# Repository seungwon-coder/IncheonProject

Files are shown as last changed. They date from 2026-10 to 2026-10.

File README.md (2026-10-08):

# PBV 생산 자동화 프로젝트 포트폴리오

PBV 생산 자동화 팀 프로젝트의 Dobot·Vision·PLC·SCADA·MES·SolidWorks 자료입니다. 본인의 Dobot Magician 4대 통합 제어와 전체 설비 조립·배치 작업, 팀원의 Vision·PLC·SCADA·MES 개발 자료를 구분해 소개합니다.

## 주요 구현
- 로봇별 독립 Worker 프로세스 및 오류 격리
- PLC·KEPServerEX OPC-UA START/READY/RUNNING/FINISH/ERROR 연동
- 수동·자동 운전 GUI, 좌표 티칭, 경로 확인
- 비전 분류 결과에 따른 반환과 차량 하부 창고 입출고
- SCADA 좌표 32개 전송 및 오래된 좌표 제외

## 읽는 순서
1. [프로젝트 개요와 담당 역할](Dobot/docs/PORTFOLIO_PROJECT_OVERVIEW.md)
2. [실행 방법과 개발 문서](Dobot/README.md)
3. [OPC-UA 태그](Dobot/docs/ROBOT_OPCUA_TAGS.md)

## 공개 범위
소스 기준: 로컬 Dobot main의 ce25ddf (2026-10-02). 공개본은 별도 새 이력으로 게시하여 비공개 저장소의 과거 이력을 포함하지 않습니다.

실제 로봇 시리얼번호, 현장 티칭 좌표, 내부 서버 IP와 재고 상태는 예시값으로 바꿨습니다. 내부 점검 메모와 제조사 SDK 바이너리/래퍼는 포함하지 않습니다. 팀 산출물은 아래 각 폴더의 공개 범위와 담당 설명을 따릅니다. 제조사 SDK는 공식 배포처에서 별도로 준비하세요. 원본 개발 문서의 SDK 포함 안내는 원본 작업 환경에 대한 설명입니다.

자동시험과 실제 설비 시운전 결과는 구분합니다. 원본 환경의 전체 자동시험은 asyncua 미설치 때문에 1개 모듈을 로딩하지 못했습니다. 공개본의 샘플 설정은 실제 장비 운전 설정이 아니며 현장 연결·티칭이 필요합니다.

일괄 오픈소스 라이선스는 부여하지 않았습니다. 코드 공개와 제3자 자료의 재배포 권한은 별개입니다.

## Vision 코드와 역할 구분
[Vision V13.29 공개용 코드·문서](Vision/README.md)를 추가했습니다. Vision 알고리즘 개발은 팀원이 담당했으며, 포트폴리오 소유자는 Dobot 제어·Vision 결과의 로봇 공정 연동과 검증·통합 지원을 담당했습니다. 모델 바이너리·전체 데이터셋·현장 운영 설정은 포함하지 않습니다. 사용 모델은 [모델 안내](Vision/MODEL_INFO.md)에 기록합니다.

### Vision V13.29 갱신
V3는 시트별 ROI에서 갈색 계열 픽셀 비율로 제품 유무를 확인하고 주문별 수량과 LED ON을 검사합니다. V1~V3 결과는 FINISH/NG/ERROR 중 하나를 1초 출력하며 V4 CLASS_RESULT 초기화는 PLC가 담당합니다. 실제 장치 경로·ROI·색상 기준은 공개용 설정에서 제거했습니다. 모델 4개와 기존 best.pt의 해시 동일성을 확인했으며 바이너리는 제외했습니다. 선택한 모의 시험 5개가 통과했고 실제 설비 운전은 이번 갱신에서 검증하지 않았습니다.

## SolidWorks 전체 설비 모델
[SolidWorks 모델링 자료](SolidWorks/README.md)를 추가했습니다. 전체 설비 조립과 장치 배치를 본인이 구성했으며 개별 부품에는 제조사 제공·참조 모델이 포함될 수 있습니다. OldVer를 제외한 원본 275개를 Git LFS로 보관합니다.

## PLC · SCADA · MES (2026-10-08 공개)
- [PLC 래더 PDF 및 날짜별 명령 CSV](PLC/README.md): 10월 2일 PDF와 9월 25일 CSV의 시점을 구분합니다. 최신 GXW 원본은 미포함입니다.
- [SCADA 보조 코드·DB 테이블·화면·운영 안내](SCADA/README.md): CIMON/KEPServer 원본 바이너리와 운영 DB는 미포함입니다.
- [MES 및 106개 태그 수집기](MES/README.md): 현재 로컬 소스를 기준으로 공개용 설정을 적용했습니다. SCADA 주문 읽기는 구현, 재생산 명령 쓰기/ACK와 ERP 전송은 미연결입니다.

SCADA·MES·PLC는 팀 산출물입니다. MES는 김동진 프로젝트 산출물을 기반으로 하며 본인의 Dobot 제어와 연결되는 지점을 설명합니다. 제품별 공정 이력과 재고 일부는 작업자 확인 기록이고 TEST/PRODUCTION은 저장 데이터 분류입니다.
공개본은 실제 계정·내부 주소·운영 데이터·로그를 제외하고 localhost 설정 예시를 사용합니다. 이번 게시에서 실제 설비 운전과 GX Works2 컴파일을 수행하지 않았습니다.

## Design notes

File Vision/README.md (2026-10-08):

# PV5 Vision V13.29 — 공개용 코드

PBV 생산 자동화 팀 프로젝트의 Vision 검사와 PLC·로봇 연동을 설명하는 공개용 선별본입니다. V13.10 공개본을 `pv5_control_hub_v13_29`의 코드로 갱신했습니다. 원본 현장 파일은 수정하지 않았습니다.

## 역할과 기여
- Vision 담당 팀원: 학습 데이터 준비, 모델 학습, 객체 검출·검사 판정 알고리즘 개발.
- 포트폴리오 소유자: Dobot 제어를 주 담당으로 맡아 PLC를 통해 전달되는 Vision 결과와 로봇 동작의 연결 조건을 검토. Vision 4 코드에 따른 Dobot_4 반환·창고 입고와 별도 출고 처리는 [Dobot 코드](../Dobot/)에 구현.
- 통합 지원: 팀장으로서 장치 간 인터페이스 조율, 공정 연동 조건·로봇 제어 로직 검증, 통합 시운전 지원.

Vision 알고리즘 개발과 로봇 연동·검증 지원은 구분하여 기록합니다.

## 검사 역할
| 구분 | 현재 판정 방식 |
|---|---|
| V1 | YOLO 램프 형상을 주문 ROUND/EDGE와 비교 |
| V2 | 검출한 시트 영역의 LAB 색상을 COCOA/DARK 기준색과 비교 |
| V3 | 시트1·시트2 ROI에서 갈색 계열 픽셀 비율로 제품 유무 판정. 주문별 시트 수량과 LED ON을 확인 |
| V4 | 단품 분류: 2 ROUND, 3 EDGE, 4 COCOA, 5 DARK, 6 차체. 빈 지그·미인식·색상 미분류·다중 부품은 0과 ERROR |

V3는 정확한 COCOA/DARK 종류나 램프 형상을 최종 판정에 사용하지 않습니다. LED 전용 ROI의 현재 밝기로 ON/OFF를 판단합니다. V13.29는 정규화 ROI 좌표를 실제 프레임 픽셀로 변환해 기준색 저장 오류를 수정합니다.

## 구조와 기능
카메라 4대 → Core 서버(카메라 단독 소유·YOLO/OpenCV 판정·OPC-UA·HTTP) → 제어판·웹·SCADA

시트1·시트2·LED 다각형 ROI 편집, 색상 기준 보정, 사용자 설정 영구 저장, OPC 자동 재연결을 지원합니다. 제어판 종료와 Core 종료는 별개입니다.

## PLC 신호 규칙
- V1~V3: 양품 FINISH, 불량 NG, 오류 ERROR 중 하나만 ON. 판정 직전 RUNNING OFF.
- V4: 정상 분류값 2~6과 FINISH, 비정상은 분류값 0과 ERROR.
- 결과 비트는 기본 1초 출력 후 OFF. PLC는 결과를 놓치지 않도록 저장해야 합니다.
- V4 CLASS_RESULT 초기화는 PLC 담당이며 Python은 JIG_Dispose를 읽거나 기다리지 않습니다.
- START OFF 확인 후 다음 ON에서 검사. 설정상 검사 제한시간 3초, 안정 판정 5프레임, V3 LED 점등 대기 0초.

## 공개용 설정과 실행
내부 IP는 localhost로, 카메라 장치 경로는 빈 값으로 바꿨습니다. 현장 ROI와 기준색은 제거했습니다. 실제 검사 전에 카메라·태그·모델·시트1/2 및 LED ROI·기준색을 설정해야 합니다. V3 객체 ROI는 빈 값이므로 그대로 정상 검사 가능한 현장 설정이 아닙니다.

```powershell
cd Vision
python -m pip install -r requirements.txt
python control_panel.py
```
Windows에서는 START_APP.vbs로 제어판을 시작할 수도 있습니다. Core 시작 후 `http://127.0.0.1:5000/`에서 4분할 영상을 확인합니다. 실제 PLC 쓰기는 기본 OFF이며 현장 검증과 작업자 승인 후 전환합니다.

기준색·ROI는 `%LOCALAPPDATA%/PV5_VISION_CONTROL/user_settings.json`에 저장되어 버전 폴더가 바뀌어도 복원될 수 있습니다. 기존 현장 설정은 별도 백업·검토하세요.

## 모델과 검증
[모델 안내](MODEL_INFO.md)에 동일 파일 여부를 기록했습니다. 모델 바이너리·전체 학습 데이터·운전 로그·현장 설정·내부 작업 프롬프트와 다른 PLC 도구 ZIP은 공개본에 포함하지 않습니다.

`test_*.py`의 일부는 이미지 처리 라이브러리나 장치 열거를 요구합니다. 전체를 장비 없는 시험으로 취급하지 않습니다. 이번 공개 작업은 문법·설정 구조와 선택한 모의 시험만 확인하며 실제 카메라·모델 정확도·PLC 연속운전을 검증한 것은 아닙니다. V13.10 이력은 Git 기록에 남습니다. 일괄 오픈소스 라이선스를 추가하지 않았습니다.

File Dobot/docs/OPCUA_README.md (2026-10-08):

# KEPServerEX OPC UA 통신

기본 접속 주소: `opc.tcp://127.0.0.1:49320`

## 실행 (Python 3.10 이상)

프로젝트 폴더에서 실행합니다.

```powershell
python -m pip install -r requirements-opcua.txt
python kepserver_opcua.py check
python kepserver_opcua.py browse --depth 3
```

ROBOT_I/O와 VISION_I/O 그룹의 태그 이름·자료형·현재 값·품질만 조회:

```powershell
python kepserver_opcua.py groups
```

특정 그룹만 조회하려면 NodeId를 지정합니다. 하위 폴더도 포함합니다.

```powershell
python kepserver_opcua.py groups "ns=2;s=M.PLC.ROBOT_I/O"
```

`None / Bad`는 유효한 현재 값을 받지 못했다는 뜻이며 0 또는 False가 아닙니다.
이 명령은 한 번 조회하고 종료합니다.

`browse` 결과에서 실제 NodeId를 복사하여 읽기/구독에 사용합니다.
아래 NodeId는 예시이며 실제 채널·디바이스·태그명과 namespace는 서버에서 확인해야 합니다.

```powershell
python kepserver_opcua.py read "ns=2;s=Channel1.Device1.Tag1"
python kepserver_opcua.py watch "ns=2;s=Channel1.Device1.Tag1"
```

`watch`는 250ms 간격을 요청하며 변경 값·품질·원본 시각을 출력합니다.
서버가 실제 간격을 조정할 수 있습니다. Ctrl+C로 종료합니다.
연결이 끊기면 오류와 함께 종료하며, 이 CLI는 자동 재연결하지 않습니다.

## 서버 설정

KEPServerEX의 OPC UA endpoint가 해당 IP와 포트에서 활성화되어 있어야 합니다.
서버 방화벽에서 클라이언트의 TCP 49320 접근이 허용되어야 합니다.
기본 실행은 익명/보안 None 연결이므로 서버가 이 구성을 허용해야 합니다.
운영 서버 보안 정책에 맞춰 다음 환경 변수/옵션을 설정합니다.

```powershell
$env:OPCUA_USERNAME = "사용자명"
$env:OPCUA_PASSWORD = "비밀번호"
$env:OPCUA_SECURITY = "Basic256Sha256,SignAndEncrypt,certs/client.der,certs/client-key.pem,certs/server.der"
python kepserver_opcua.py check
```

인증서는 별도 발급이 필요하며 KEPServerEX에서 클라이언트 인증서를 신뢰하도록
등록해야 합니다. `--application-uri`는 클라이언트 인증서의 Application URI와
일치시킵니다. 암호를 코드나 저장소에 기록하지 마세요.

## 기존 공정 코드와 연결

`OpcUaBackend`는 기존 `OpcConnectionManager` 인터페이스를 구현합니다.
실제 주소 매핑을 확정한 뒤 아래처럼 생성하여 사용합니다.

```python
from opcua_backend import OpcUaBackend
from opc_connection_manager import OpcConnectionManager

node_map = {"D1011": "ns=2;s=Channel1.Device1.WorkCount"}  # 실제 NodeId로 교체
connection = OpcConnectionManager(lambda: OpcUaBackend(node_map=node_map))
try:
    if connection.connect_if_due():
        print(connection.read(["D1011"]))
finally:
    connection.close()
```

공정 루프에서 `connect_if_due()`를 반복 호출하면 기존 관리자의 재접속 규칙을
사용할 수 있습니다. GUI 스레드가 아닌 작업 스레드에서 호출하세요.
GUI/실제 공정에 대한 자동 연결은 추가하지 않았습니다.

`backend.write({NodeId: value})`는 서버의 자료형으로 값을 기록합니다.
여러 태그 쓰기는 순차 처리이며 일부만 성공할 수 있습니다. 실패한 명령을
자동 재전송하지 않으며 실제 설비 쓰기는 이 점검 프로그램에서 실행하지 않습니다.

## 검증

```powershell
python -m unittest tests.test_opcua_backend tests.test_opc_connection_manager -v
```

로컬 시험 서버로 읽기·Int16 쓰기·구독·없는 노드 오류를 검사합니다.

참고: [asyncua 공식 문서](https://opcua-asyncio.readthedocs.io/en/latest/)

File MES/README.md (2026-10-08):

# SCADA 연동 학습 MES - 공개용 소스

2026-10-08 로컬 project-mes 및 data_collect_all 기준. 팀 산출물이며 MES 출처는 김동진 프로젝트 산출물입니다. SCADA/MES 개발 전체를 포트폴리오 소유자의 단독 개발로 표시하지 않습니다.

## 구성과 현재 구현
- manufacturing/collector.py: 로봇 57, Vision 24, 주문 21, 라인 상태 4개, 총 106개 태그 수집 설계. 250ms 요청 변경값 구독, MySQL 최신값/이력, SQLite 임시 저장.
- manufacturing/mes: 주문·제품별 작업자 확인 기록, 재고, 검사 승인 및 PDF 보고서, NG 재생산 큐.
- scada_sync.py: smart_factory 주문·상품·생산 이력 읽기. MES DB에만 기록하며 SCADA 생산 명령은 쓰지 않습니다.
- SCADA 재생산 명령/수신 확인 및 ERP 전송은 WAITING_CONFIG 상태이며 미연결입니다.
- TEST/PRODUCTION은 데이터 분류입니다. PLC 운전 모드를 변경하지 않습니다.
- 제품별 공정 이력과 재고 일부는 작업자 입력입니다. 제품 추적 ID에 따른 전자동 연계는 구현되지 않았습니다.

## 실행 준비 (Windows)
1. Python, MySQL 및 requirements.txt 의존성을 준비합니다. 원본 환경의 정확한 Python 운용 버전은 이 패키지에서 재검증하지 않았습니다.
2. config.example.json을 config.json으로 복사하고 mysql_exe와 시험용 OPC UA endpoint를 설정합니다.
3. mysql-client.example.ini를 mysql-client.ini로 복사해 본인의 별도 테스트 DB 계정을 설정합니다.
4. MySQL에서 manufacturing/schema.sql, mes/schema.sql, mes/initialize-empty-inventory.sql 순서로 적용합니다. 초기 재고는 0이며 GUI에서 시험값을 입력합니다.
5. mes/scada-source.example.json을 scada-source.json으로 복사합니다. enabled=false가 기본입니다. SCADA 읽기 연동 사용 시에만 별도 읽기 계정과 scada-client.ini를 준비합니다.
6. manufacturing에서 `python collector.py`, 별도 터미널에서 `python mes/app.py` 실행 후 http://127.0.0.1:8765 접속합니다. 종료는 각 터미널에서 Ctrl+C.

공개용 사본은 웹 접속을 localhost로 제한했습니다. 화면의 작업자/관리자 선택은 로그인 인증이 아닙니다. 운영 네트워크 배포용 인증 서비스가 아닙니다.
실제 OPC UA 서버 태그, DB, MySQL 실행 파일이 없으면 설비 상태를 읽을 수 없습니다. 이 ZIP은 독립 실행형 설치 프로그램이 아닙니다.

## 공개용 변경
- 실제 계정/INI, 운영 DB, 로그, spool, 보고서, 수집 상태, 초기 주문 목록, 개인 PC 실행 파일을 제외.
- 내부 IP는 localhost 예시로 변경. 웹 LAN 바인딩 제거.
- 실제 운영 데이터 없이 테이블 정의만 제공. 초기 재고는 0.
- 기존 57개 태그 초기 버전과 구 github-upload 사본 대신 최신 106개 태그 및 MES 소스를 사용.
- 원본 수정 없음. 검증은 구문/구성/비공개 값 검사이며 실제 설비 운전 검증은 수행하지 않았습니다.

## 소스 출처와 담당 구분
원본: 프로젝트산출물_프로그래밍_김동진/MES.customDB/project-mes 및 data_collect_all.
프로젝트 인수인계에는 MES 팀원 저장소 inc6f4i/scada-mes, 참조 커밋 cbf1c4d가 기록되어 있습니다. 본 ZIP은 해당 원격 커밋과 동일함을 뜻하지 않습니다.
포트폴리오 소유자의 Dobot 제어 작업과 MES의 설비 상태 수집을 연결 지점으로 설명하며, SCADA/MES 직접 개발·시험 성과는 확인된 담당 범위와 증빙에 따라 별도로 표기해야 합니다.

## 포트폴리오 자료
- [DB 구조·연동 설명](docs/MES_DB_구조_및_연동설명.pdf)
- [주요 화면](screenshots/)
- [SCADA·MES 프로젝트 소개](../SCADA/docs/SCADA_MES_프로젝트_소개.pdf)

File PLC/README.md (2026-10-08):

# PLC 래더 및 공정 연동 자료

PBV 조립 공정 PLC 프로그램의 공개용 자료입니다. PLC 개발은 팀 산출물로 표시하며 포트폴리오 소유자의 Dobot 통합 제어와 연결되는 신호를 설명합니다.

## 읽는 순서
1. [2026-10-02 래더 PDF - 69쪽](docs/PLC_래더_2026-10-02.pdf)
2. [2026-09-25 GX Works2 CSV 내보내기 - 9개](ladder-export/2026-09-25/)
3. [Dobot OPC UA 태그](../Dobot/docs/ROBOT_OPCUA_TAGS.md)
4. [SCADA 구축·운영 자료](../SCADA/README.md)

## 버전 구분
| 자료 | 시점 | 용도 |
|---|---|---|
| 래더 PDF | 원본 출력일 2026-10-02 | 프로그램 설정 및 래더 확인 |
| CSV 9개 | 원본 폴더 2026.09.25, 일부 파일 저장일 09-26 | 당시 1_Main~9_servo의 명령·디바이스·주석 확인 |
| 비공개 incheonProject_Final.gxw | 로컬 수정일 2026-10-06 | 최종 이름의 원본. 이번 공개본에 미포함 |

PDF와 CSV는 서로 다른 시점입니다. 둘을 10월 6일 GXW 최종본의 동일한 내보내기로 간주하지 않습니다. CSV는 원본의 탭 구분 형식을 유지하고 UTF-16에서 UTF-8로 변환했습니다. 확장자는 원본 .csv를 유지합니다.

## 공정과 Dobot 연동
프로젝트 문서의 PLC 장비는 Q03UDECPU, QX41, QY81P, QD75D1N, QJ71E71-100입니다.
CSV는 Main·Body·Lamp·Seat·Robot·Vision·Return·Vision4/회수·Servo 프로그램으로 구분됩니다.
SCADA 최종 재구축 문서 기준 프로그램 선택은 D0, 생산 START는 M90의 500ms 펄스입니다. Dobot는 OPC UA START/READY/RUNNING/FINISH/ERROR 태그로 공정을 연계합니다. 실제 태그 주소는 각 시점의 PLC 프로젝트와 대조해야 합니다.

## 공개 범위와 검증
69쪽 래더 PDF의 전체 텍스트와 CSV 9개에서 내부 IP, 암호 관련 표현, 개인 사용자 경로를 검사했습니다.
원본 232쪽 전체 PDF에는 내부 주소 및 암호 관련 설정 페이지가 있어 제외했습니다. GXW·HMI·서보 설정·과거 시험 프로젝트는 이번 공개 범위에 포함하지 않았습니다.
원본은 수정하지 않았습니다. 실제 GX Works2 열기·컴파일·PLC 다운로드·장비 시운전은 수행하지 않았습니다.

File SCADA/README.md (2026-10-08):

# SCADA 공개용 선별 자료

2026-10-08 SCADA/최종 자료 기준. CIMON SCADA 프로젝트는 팀 산출물입니다.

## 포함
- helpers/VISION_MJPEG_RELAY_4CH.py: Vision 4채널 MJPEG 화면 중계 보조 코드. 기본 주소는 localhost 예시.
- helpers/ROBOT_TCP_WATCH.py: SCADA PC의 TCP Established 연결 여부를 상태 파일로 기록하는 보조 코드. 로봇 동작 성공·안전 상태를 판정하는 코드가 아닙니다.
- database/smart_factory_tables.sql: 원본 백업에서 추출한 7개 테이블 정의. 운영 주문, 사용자 계정, 생산 이력, 실제 데이터는 없습니다. 원본의 7개 뷰와 CIMON 생산 제어 스크립트는 포함하지 않습니다.

## 생산 제어 구조
CIMON 생산 화면/스크립트와 KEPServer 태그가 실제 구성의 중심입니다. ORDER.PLC_PROGRAM_NO는 D0, ORDER.PLC_START는 M90에 연결되며 START는 500ms 펄스입니다.
최종 정상 완료는 ROBOT_FINISH_3(M1023), NG는 VISION3_NG(M1124) 기준입니다. 기존 D200 설명 및 Python PLC_FINISH/Quick Client 시험 코드를 최종 생산 구현으로 해석하지 않습니다.

## 범위
이 ZIP은 SCADA 전체 복원본이나 CIMON 설치 파일이 아닙니다. PGX/SCX/PRJ/OPF 등 원본 바이너리 프로젝트와 실제 DB 백업은 계정·내부 설정이 포함될 수 있어 비공개 원본으로 보관했습니다. 실제 CIMON 프로젝트의 화면·스크립트 복원에는 비공개 원본과 정식 실행 환경이 필요합니다.
로컬 원본은 수정하지 않았습니다. 보조 코드는 실행하면 네트워크 읽기와 상태 파일 기록이 시작되므로 시험 환경 설정 후 사용합니다. 본 공개 준비에서 실행하지 않았습니다.

## 담당 구분
SCADA 구축은 팀 산출물로 표기합니다. 포트폴리오 소유자의 Dobot 제어 코드와 연결되는 태그/상태를 설명할 수 있으나 SCADA 전체 개발을 단독 기여로 주장하지 않습니다.

## 포트폴리오 자료
- [SCADA·MES 프로젝트 소개](docs/SCADA_MES_프로젝트_소개.pdf)
- [SCADA 구축·운영 안내](docs/SCADA_구축_운영_안내_공개용.pdf)
- [주요 화면](screenshots/)
- [MES 및 106개 태그 수집기](../MES/README.md)
- [PLC 래더 자료](../PLC/README.md)

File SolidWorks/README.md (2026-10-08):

# SolidWorks 전체 설비 모델링

[Source/테이블_최종](Source/테이블_최종/)에 전체 설비 조립 모델과 부품 275개를 보관합니다.
최상위 조립 파일은 공정구상도_수정중.SLDASM입니다. OldVer 및 SolidWorks 잠금 임시 파일은 제외했습니다.

## 담당 범위
본인이 전체 설비 조립 모델을 구성하고 장치를 배치했습니다. 개별 부품에는 제조사 제공 및 참조 모델이 포함될 수 있으며, 모든 부품을 직접 제작했다는 의미는 아닙니다. 일괄 오픈소스 라이선스를 추가하지 않았습니다.

## 내려받기
Git LFS 설치 후 저장소를 복제하고 git lfs pull을 실행하세요. 폴더 전체를 유지해 최상위 조립 파일을 여세요.

## 확인 범위
원본 275개의 SHA256을 검증했습니다. SolidWorks에서 외부 참조·누락 부품·간섭·정상 재생성을 검증하지 않았습니다. 원본 CAD를 재저장하지 않아 파일 내 작성 정보나 참조 경로가 남아 있을 수 있습니다. PDF의 교육용 표시는 원본 그대로 유지했습니다.

## 자료
- 공정테이블.pdf 및 공정테이블_1.pdf: Source/테이블_최종/에 포함
- 전체 조립과 부품 원본: Source/테이블_최종/
- 설계·파일 안내: 모델링_안내.txt

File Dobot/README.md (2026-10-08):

# 공개용 Dobot 코드 안내

이 복사본은 포트폴리오 공개용입니다. 실제 현장 좌표는 제거되어 모든 티칭 포인트가 미티칭 상태이고, 시리얼번호와 OPC-UA 주소는 예시값입니다. 아래 원본 개발 문서의 현장 적용 기록은 개발 당시 설명이며 공개본 기본 설정과 구분해야 합니다.

제조사 SDK와 DLL은 재배포 권한을 확인하지 못해 포함하지 않습니다. 실제 실행에는 공식 Dobot SDK 및 드라이버를 별도 준비하여 `sdk/`에 배치해야 합니다. `DobotDllType.py`와 DLL 파일명은 아래 개발 문서를 참고하세요.

# DobotControl Main

## 팀원용 빠른 시작

이 프로젝트는 PC 한 대에서 Dobot Magician 4대를 각각 독립 Worker 프로세스로
제어하고, KEPServerEX OPC-UA를 통해 Mitsubishi PLC와 START 및 상태 신호를
교환합니다. 처음 실행하는 팀원은 아래 순서를 지켜 주세요.

채용 포트폴리오용 프로젝트 개요와 담당 역할, 핵심 설계 내용은
[`docs/PORTFOLIO_PROJECT_OVERVIEW.md`](docs/PORTFOLIO_PROJECT_OVERVIEW.md)에서 확인할 수 있습니다.

```powershell
cd ./Dobot
python -m pip install -r requirements-opcua.txt
python -m unittest discover -s tests -v
python -m manual_tests.dobot_connection_test
python .\dobot_port_recovery.py
python -m manual_tests.dobot_identity_test
python -m manual_tests.multi_dobot_status_test
python .\integrated_gui.py
```

`tests`는 실제 장비 없이 실행됩니다. `manual_tests`는 실제 USB 장비를 사용하므로
한 번에 한 프로그램만 실행하고, `--execute`가 붙은 명령은 주변 간섭과 비상정지를
확인한 경우에만 실행합니다. PC 또는 로봇 전원을 다시 켠 뒤 COM 번호가 바뀌면
반드시 `dobot_connection_test → dobot_port_recovery → identity/status` 순서로 확인합니다.

전체 실행 흐름은 다음과 같습니다.

```text
PLC/KEPServerEX
  │ START 입력 / RUNNING·FINISH·ERROR·READY 및 좌표 32개 출력
  ▼
communication/automatic_operation.py   ← 수동·자동 공용 OPC-UA 스레드
  ▼
robot_control/live_process_manager.py   ← 신호 상태와 실제 공정 결합
  ▼
robot_control/process_state_machine.py  ← 로봇별 기동 조건과 상태 전이
  ▼
robot_control/robot_motion_controller.py← 티칭 이름을 안전 이동 순서로 변환
  ▼
robot_control/dobot_worker.py           ← 로봇별 별도 프로세스와 제조사 SDK
  ▼
Dobot Magician 1~4
```

팀원이 먼저 읽을 핵심 파일은 다음과 같습니다.

| 파일 | 역할 |
|---|---|
| `config/robots.json` | 로봇 이름, 현재 COM, 시리얼번호, 공구, 필수 포인트 목록 |
| `config/teaching_points.json` | GUI에서 저장한 실제 X/Y/Z/R과 포인트별 속도 |
| `integrated_gui/integrated_gui.py` | 4대 연결, 수동·자동 운전 및 PLC 신호 화면 |
| `communication/robot_opcua_tags.py` | KEPServerEX 실제 NodeId의 단일 관리 위치 |
| `communication/robot_position_opc.py` | SCADA용 X/Y/Z/R/J1~J4 좌표 32개 전송 |
| `robot_control/live_process_manager.py` | READY/RUNNING/FINISH/ERROR 결정 위치 |
| `robot_control/robot_motion_controller.py` | HOME, 픽업, 조립·반환, ready 복귀 순서 |
| `manual_tests/` | 실제 장비를 단계별로 확인하는 작업자용 검사 |
| `tests/` | 장비 없이 회귀 오류를 찾는 자동 테스트 |

루트의 `integrated_gui.py`, `teaching_gui.py`, `dobot_config.py`,
`dobot_port_recovery.py`, `kepserver_opcua.py`는 기존 실행 명령을 유지하기 위한
짧은 진입점입니다. 실제 기능을 수정할 때는 각 패키지 안의 파일을 수정합니다.

## 프로젝트 폴더 구조

기능별 코드는 다음 Python 패키지로 구분한다. 루트의 짧은 실행 파일은 기존
명령을 유지하기 위한 진입점이며, 실제 기능은 각 패키지 안에 있다.

```text
DobotControl_Main/
├─ sdk/              제조사 Python 래퍼, 제어 DLL 및 의존 DLL
├─ robot_control/    실제 Dobot 연결, Worker, JOG, PTP 및 공정 제어
├─ teaching/         PC·모바일 티칭 GUI와 티칭 포인트 관리
├─ integrated_gui/   Dobot 4대 통합 상태 및 수동·자동 운전 화면
├─ communication/    PLC, KEPServerEX 및 OPC-UA 통신
├─ config/           로봇 등록 정보와 티칭 좌표
├─ tests/            실제 장비가 필요 없는 자동 테스트
├─ manual_tests/     실제 장비를 사용하는 단계별 시험
├─ logs/             USB 연결 검사 결과
└─ docs/             OPC-UA 및 코드 분석 문서
```

자주 사용하는 실행 명령은 폴더 정리 전과 동일하다.

```powershell
python .\teaching_gui.py
python .\integrated_gui.py
python .\dobot_port_recovery.py
python .\kepserver_opcua.py --help
```

내부 코드를 새로 작성할 때는 루트 실행 파일이 아니라 `robot_control`,
`teaching`, `integrated_gui`, `communication` 패키지에서 가져온다.

## 수동 / 자동 운전 모드

티칭 GUI 하단의 **6. 실제 1사이클 이동 포인트 순서**에서 선택한 로봇의
목적지별 이동 경로를 확인할 수 있습니다. Dobot_2는 assembly_1/assembly_2,
Dobot_4는 제품·적층 목적지를 선택할 수 있습니다. 각 포인트 옆에는 저장 속도에
수동 검증 사이클 최대 10% 제한을 적용한 요청 속도가 표시됩니다. PLC START로
실행되는 자동모드는 저장 속도를 그대로 따르되 최대 30%로 제한합니다.

`python integrated_gui.py`로 실행합니다. 기본값은 수동 모드입니다.

- **수동 모드**: 실제 4대 연결이 끝나면 OPC-UA 연결도 시작되어 PLC START를 읽고
  RUNNING/FINISH/ERROR/READY를 계속 기록합니다. PLC START는 GUI에 표시만 하며
  로봇을 자동 기동하지 않습니다. 실제 기동은 GUI의 수동 버튼으로만 실행합니다.
  Dobot_2는 수동 기동 전에 `첫 번째 조립` 또는 `두 번째 조립`을 선택해 해당
  조립 위치의 1사이클을 실행합니다. 자동모드는 PLC의 목표·완료 카운트로
  조립 위치를 결정하므로 이 화면 선택값을 사용하지 않습니다.
  통합 GUI의 `선택 로봇 실제 1사이클 실행`은 이동이 시작되면 RUNNING을 켜고
  사이클 완료 시 내립니다. 별도 티칭 GUI의 개별 PTP/JOG 이동은 이 PLC 공정
  신호에 포함되지 않습니다.
- OPC-UA가 끊겼거나 `BadShutdown`이 발생하면 KEPServerEX 상태를 확인한 뒤
  `OPC-UA 연결/재연결`을 누릅니다.
  이 두 버튼은 Dobot의 USB/COM 연결을 해제하지 않습니다. 재연결 전 작업자가
  READY를 승인한 대기 로봇만 PLC READY를 다시 켜며, 자동모드는 작업자가 다시
  선택해야 합니다. 통신이 끊긴 동안의 FINISH는 재전송하지 않으므로 PLC 완료
  카운트를 확인하세요.
- **자동 모드 (PLC 기동)**: 실제 4대 연결 후 각 로봇의 작업자 READY 승인을 마친 대기 상태에서 선택합니다.
- 기계적 HOME을 실행하지 않아도 통합 GUI에서 로봇을 선택하고
  `선택 로봇 PLC READY 승인`을 누르면 해당 로봇의 PLC READY를 켭니다.
  이 버튼은 위치·알람을 자동 검사하거나 로봇을 이동시키지 않습니다.
  현재 위치와 주변 간섭 여부는 작업자가 확인해야 합니다. 운전 중·오류 상태에서는
  승인할 수 없으며, 사이클 완료 후 READY는 기존처럼 자동으로 켜집니다.
  PLC START를 약 250ms 대기 간격으로 반복 조회합니다(통신 시간만큼 실제 주기는 늘어납니다).
  START는 RUNNING ON을 확인할 때까지 유지하고, 확인 후 OFF로 내리세요.
  짧은 펄스는 놓칠 수 있습니다. 실행 중 다음 작업을 예약할 때도 START OFF가
  읽힌 뒤 새 ON을 보내야 합니다. 예약된 작업은 FINISH OFF·READY ON 후 실행됩니다.
- 자동 진입 시 이미 ON인 START는 실행하지 않습니다. OFF를 관측한 뒤 새 ON부터 기동합니다.
- 각 로봇은 독립 실행합니다. 실행 중 들어온 새 START 상승 에지는 로봇별로
  다음 작업 한 건만 예약하고, 그 이상의 요청은 무시합니다. 수동 전환·통신 종료·
  해당 로봇 오류 시 예약은 취소됩니다. 기존 PLC 태그에는 예약 접수 확인 신호가 없습니다.
- Dobot_1은 재료를 집어 `pickup_approach`로 상승한 뒤 `ready`를 경유하여
  `assembly_1_approach`로 이동합니다. 조립 완료 후에도 기존과 같이 `ready`로 복귀합니다.
- Dobot_2는 START 수락 시 `ROBOT2_TARGET_COUNT`(1 또는 2)와
  `ROBOT2_FINISH_COUNT`(0 이상, 목표 미만)를 읽습니다. 완료 0이면 assembly_1,
  완료 1이면 assembly_2를 한 번 실행합니다. `ROBOT_Program_NO_(2)`는 기동 조건에
  사용하지 않습니다. 횟수 증가/초기화는 PLC가 담당합니다. 목표 2·완료 0인
  첫 조립 중 추가 START는 예약하지 않습니다. 첫 FINISH를 PLC가 카운트한 뒤
  목표 2·완료 1에서 새 START를 보내야 두 번째 조립이 시작됩니다. 마지막 조립
  중 추가 START만 다음 제품용으로 한 건 예약합니다. 이전 FINISH 펄스가 끝난 뒤
  PLC의 목표/완료 `0/0` 초기화를 Python이 관측하고, 새 제품의 목표 1 또는 2·
  완료 0이 30초 안에 준비되어야 예약 공정이 시작됩니다. `0/0` 상태가 OPC-UA
  조회 사이에 지나가면 예약은 실행되지 않으므로 충분히 유지해야 합니다.
- Dobot_2의 첫 번째 조립은 `pickup_approach → safe_point →
  assembly_2_approach → assembly_1_approach → assembly_1` 순서로 진입합니다.
  두 번째 조립은 `pickup_approach → safe_point → assembly_2_approach →
  assembly_2`로 진입합니다. 첫 번째 조립 후에는 복귀 전용
  `assembly_1_approach2 → safe_point → ready`를 사용합니다. 이 새 포인트는
  티칭 GUI에서 실제 좌표를 저장하기 전까지 첫 번째 조립 사이클을 차단합니다.
  두 번째 조립 후에는 기존처럼 `assembly_2_approach → safe_point → ready`로
  복귀합니다.
- Dobot_4는 START 상승 순간 `ns=2;s=M.PLC.VISION_I/O.VISION4_CLASS_RESULT`를
  한 번 읽어 경로를 고정합니다. 코드 2/3/4/5/6은 각각 Lamp_a/Lamp_b/
  Seat_a/Seat_b/Main이며, 그 밖의 값이면 이동하지 않고 ERROR를 출력합니다.
- Dobot_3은 `ready → pickup_approach_1 → pickup` 순서로 흡착하러 들어가고,
  흡착 후에는 `pickup_approach_1 → pickup_approach_2`로 빠져나옵니다.
- Dobot_4의 Lamp_a·Lamp_b·Seat_a·Seat_b 공급은 `jig_pickup_approach`로
  픽업 위치에서 나온 뒤 `ready`를 거쳐 해당 반환 위치 상부로 이동합니다.
  Main 경로는 기존 순서를 유지합니다.
- Dobot_4 차량 하부 창고는 최대 3개 적층 방식입니다. 자동 모드 전에 GUI에서
  실제 재고 0~3을 입력하고 `재고 확정`을 눌러야 합니다. 비전 코드 6으로 차량
  하부를 반환할 때 현재 재고 0/1/2에 따라 각각 `storage_base_1st/2nd/3rd`에
  놓으며, `ready` 복귀까지 정상 완료된 후에만 재고를 1 증가시킵니다. 3개이면
  `가득 참` 오류로 이동 전에 차단합니다.
- 자동운전 중에도 Dobot_4가 대기 상태라면 작업자가 실제 창고에 차량 하부를
  수동으로 넣거나 꺼낸 뒤 GUI의 수량을 0~3으로 수정하고 `재고 확정`을 누를 수
  있습니다. Dobot_4 입고·출고 사이클 실행 중에는 수량 변경을 차단합니다.
- `storage_base_1st/2nd/3rd`와 각 층 전용 상부점
  `storage_base_1st_approach`, `storage_base_2nd_approach`,
  `storage_base_3rd_approach`를 티칭 GUI에서 실제 높이로 티칭해야 합니다.
  기존 `storage_base_approach` 좌표는 `storage_base_1st_approach`로 이전했으며,
  새 2층·3층 상부점은 실제 좌표를 티칭하기 전까지 해당 사이클을 차단합니다.
- Dobot_4의 `ROBOT_START(B)_(4)` 상승 에지가 들어오면 현재 재고의 최상단
  `storage_base_3rd/2nd/1st`를 선택하여 `ready → 선택 층 전용 approach →
  선택 적층점 → 같은 층 approach → main_conveyor_approach →
  main_conveyor → main_conveyor_approach → ready` 순서로 차량 하부를 공급합니다.
  정상 완료 후에만 재고를 1 감소시키고 `ROBOT_FINISH(B)_(4)`를 약 1초간
  출력합니다. 재고가 0이면 이동 전에 ERROR로 차단합니다.
- `ROBOT_START_(4)` 입고 사이클과 `ROBOT_START(B)_(4)` 출고 사이클은 같은
  Dobot_4를 사용하므로 동시에 실행하지 않습니다. 실행 중 들어온 다음 START는
  종류와 관계없이 한 건만 예약합니다.
- RUNNING/FINISH/READY/ERROR를 PLC에 기록합니다. FINISH는 사이클 완료 후
  OPC-UA에 ON을 기록한 때부터 약 1초간 유지한 뒤 자동으로 OFF로 전환합니다.
  START의 OFF 여부와 무관하며, PLC는 FINISH 상승 에지를 한 번 카운트해야 합니다.
- 수동 전환 시 새 기동을 차단하고 진행 공정 종료 및 마지막 상태 전송 후 수동으로 돌아옵니다.
  즉시 정지는 별도 GUI 비상정지 버튼입니다. 일시정지 중이면 재개 또는 정지로 공정을 끝내야 합니다.
- 통신/품질/카운터 오류 시 자동 모드를 종료합니다. 진행 중 공정은 완료를 기다립니다.
  통신이 끊기면 PLC로 오류 상태를 전송할 수 없으므로 PLC 측 통신 감시도 필요합니다.
- 자동 감시 중 수동 기동/초기화/연결 변경/입력 변경은 비활성화됩니다.
- 수동·자동은 같은 OPC-UA 연결을 공유합니다. 자동 모드 전환은 연결을 새로 만들지
  않고 PLC START의 실제 기동 허용 여부만 바꿉니다.
- 각 로봇 카드에는 PLC의 START 입력과 Python이 보내는 RUNNING/FINISH/ERROR/READY가
  ON/OFF로 표시됩니다. 작업자가 READY를 승인하면 수동 모드에서도 READY를
  KEPServerEX에 계속 기록합니다.
- 이동 없는 작업 초기화 뒤에는 READY를 OFF로 유지합니다. 작업자가 다시 승인하면
  HOME 이동 없이 READY가 ON 됩니다.
- 실제 4대 연결이 성공하면 SCADA 좌표 전송도 자동으로 시작됩니다. START·상태·좌표는
  KEPServerEX OPC-UA 연결 하나를 공유합니다. 기존 Worker가
  읽은 실제 X/Y/Z/R/J1~J4만 공유하므로 추가 COM 연결이나 이동 명령은 없습니다.
  KEPServerEX에는 `M.PLC.ROBOT_I/O.Coord.ROBOT1_X`부터 `ROBOT4_J4`까지 총
  32개 Float 태그를 약 1초 간격으로 기록합니다.
- 좌표가 3초 이상 갱신되지 않은 로봇은 오래된 값을 다시 쓰지 않고 해당 로봇만
  이번 전송에서 제외합니다. 통신 오류가 나도 로봇 제어는 중단하지 않고 재접속합니다.

SCADA와 같은 좌표 태그를 PowerShell에서 읽기 전용으로 확인하려면 실행합니다.

```powershell
python -m manual_tests.opcua_robot_positions
```

검증: `python -m unittest tests.test_automatic_operation tests.test_gui_operation_modes -v`
개발 중 실제 로봇 기동 및 PLC 상태 쓰기는 수행하지 않았습니다.

### PLC 신호 상태표

| 상황 | START | RUNNING | FINISH | ERROR | READY |
|---|---:|---:|---:|---:|---:|
| 연결 직후, HOME 전 | PLC 입력 | OFF | OFF | OFF | OFF |
| HOME 및 ready 이동 중 | PLC 입력 | ON | OFF | OFF | OFF |
| ready 위치에서 대기 | PLC 입력 | OFF | OFF | OFF | ON |
| 공정 실행 중 | PLC 입력 | ON | OFF | OFF | OFF |
| 공정 완료 후 ready 복귀, 약 1초 | PLC 입력 | OFF | ON | OFF | ON |
| FINISH 펄스 종료 후 | PLC 입력 | OFF | OFF | OFF | ON |
| 오류·비상정지 | PLC 입력 | OFF | OFF | ON | OFF |
| 이동 없는 작업 초기화 | PLC 입력 | OFF | OFF | OFF | OFF |

START는 PLC가 Python으로 보내는 입력이고 나머지 네 신호는 Python이 PLC로 보내는
출력입니다. 수동 모드에서는 START를 읽고 GUI에만 표시하며 자동 기동하지 않습니다.
자동 모드로 전환할 때 이미 ON인 START도 실행하지 않고, OFF를 확인한 다음 새 ON부터
한 번만 실행합니다.

### KEPServerEX 읽기 전용 확인

```powershell
python .\kepserver_opcua.py check
python .\kepserver_opcua.py browse --depth 3
python .\kepserver_opcua.py groups "ns=2;s=M.PLC.ROBOT_I/O"
python -m manual_tests.opcua_start_status
```

4대 READY만 확인하려면 다음 명령을 사용합니다.

```powershell
python .\kepserver_opcua.py read `
  "ns=2;s=M.PLC.ROBOT_I/O.ROBOT_READY_(1)" `
  "ns=2;s=M.PLC.ROBOT_I/O.ROBOT_READY_(2)" `
  "ns=2;s=M.PLC.ROBOT_I/O.ROBOT_READY_(3)" `
  "ns=2;s=M.PLC.ROBOT_I/O.ROBOT_READY_(4)"
```

기본 서버 주소는 `opc.tcp://127.0.0.1:49320`입니다. 실제 태그 이름은
`communication/robot_opcua_tags.py`에서만 관리하며 다른 파일에 중복 작성하지 않습니다.

## 검사 코드 폴더 구분

- `tests/`: 실제 Dobot 없이 가짜 Worker로 실행하는 자동 단위 테스트
- `manual_tests/`: 사용자가 통신·상태·JOG·HOME·공정 경로를 개별 점검하는 스크립트

`manual_tests`는 MAIN 폴더에서 `python -m manual_tests.파일이름` 형식으로 실행합니다.
파일에 `--execute`가 있는 경우 이 옵션을 생략하면 실제 이동을 하지 않습니다.

## USB 통신 점검

### 수동 PTP 속도 조절

티칭 GUI의 **5. 티칭 포인트 저장 및 이동**에서 **수동 PTP 속도(5~100%)**를
입력하고 **선택 포인트로 이동**을 누릅니다. 기본값은 5%이며 0.1% 단위로 조절합니다. 확인 창에 표시된
속도로 이동합니다. 입력값 변경은 다음 이동부터 적용됩니다.
이 속도는 JOG 속도, 포인트에 저장된 속도, 자동운전 속도와 독립적입니다.
범위를 벗어나거나 숫자가 아닌 값은 이동 전에 차단합니다.
장비에서 확인된 PTP 지원 범위인 5~100%를 common ratio에 그대로 적용하며,
분할 이동이나 인위적인 정지 시간은 사용하지 않습니다. 관절·직교 기준속도는
현재 장비 값을 유지합니다. 속도 설정과 이동을 같은 큐에 순서대로 등록해 실행합니다.
실행 전 common 조회값과의 비교는 하지 않으며, 완료 화면에는 요청 속도를 표시합니다.
`7`과 `7.0`은 모두 같은 7% 요청입니다.

### 연결 진단

`manual_tests/dobot_connection_test.py`는 로봇을 움직이지 않고 Dobot USB 통신만 확인합니다.
Main 내부의 `sdk/DobotDllType.py`와 `sdk/DobotDll.dll`을 사용합니다.
`sdk/`에는 Qt 및 Visual C++ 의존 DLL도 포함되어 있어 `DobotControl_Test` 폴더 없이
Main을 사용할 수 있습니다. Python 의존 패키지와 장비 USB 드라이버는 PC별로 설치해야 합니다.
연결 진단과 포트 복구도 기본적으로 이 내부 SDK를 사용하며, `--sdk-dir`로 변경할 수 있습니다.

```powershell
python -m manual_tests.dobot_connection_test
```

특정 포트만 검사하려면 다음과 같이 실행합니다.

```powershell
python -m manual_tests.dobot_connection_test --ports COM3 COM4 COM5 COM6
```

포트 한 개가 응답하지 않을 때 기다릴 시간은 기본 8초입니다. 다음처럼 변경할 수
있습니다. 한 포트가 멈춰도 제한 시간이 지나면 실패로 기록하고 다음 포트를 계속
검사합니다.

```powershell
python -m manual_tests.dobot_connection_test --port-timeout 10
```

성공 조건은 기본적으로 4대 모두 연결되는 것입니다. 결과는 `logs` 폴더에 JSON으로
저장됩니다. 이 점검에서는 HOME, JOG, PTP, 그리퍼, 흡착컵 명령을 전송하지 않습니다.

## 로봇 등록

물리적인 로봇을 확인한 뒤 각 포트를 명시적으로 등록합니다. 포트를 임의로 지정하면
다른 로봇이 움직일 수 있으므로 실제 장비와 대조한 후 실행해야 합니다.

```powershell
python .\dobot_config.py --assign Dobot_1 COM14
python .\dobot_config.py --assign Dobot_2 COM11
python .\dobot_config.py --assign Dobot_3 COM13
python .\dobot_config.py --assign Dobot_4 COM15
```

등록 상태만 확인하려면 인자 없이 실행합니다.

```powershell
python .\dobot_config.py
```

## 4대 동시 상태 확인

네 포트를 모두 등록한 후 실행합니다.

```powershell
python -m manual_tests.multi_dobot_status_test
```

각 Dobot은 별도 프로세스에서 SDK를 로드하므로 SDK의 전역 장치 ID가 서로 충돌하지
않습니다. Worker는 연결·상태 읽기뿐 아니라 검증된 JOG, PTP, HOME, 큐 및 공구 명령도
처리합니다. 모든 명령은 시간 제한과 입력 검사를 거치며 무응답 Worker는 종료됩니다.

한 Worker 장애가 나머지 Dobot에 전파되지 않는지 시험하려면 다음을 실행합니다.
로봇 이동 없이 Dobot_1의 Python Worker만 종료한 후 자동 복구를 확인합니다.

```powershell
python -m manual_tests.worker_isolation_test
```

## 설정 자동 테스트

포트와 엔드이펙터 매핑이 정확히 저장되는지 실제 로봇을 움직이지 않고 검사합니다.

```powershell
python -m unittest tests.test_dobot_config -v
```

## 장치 고유 식별정보 확인

COM 포트가 바뀌었을 때 자동으로 같은 Dobot을 찾을 수 있는지 확인합니다. 로봇은
움직이지 않으며 SDK 시리얼번호와 장치명만 읽습니다.

```powershell
python -m manual_tests.dobot_identity_test
```

## 변경된 COM 포트 자동 복구

최초 등록된 네 Dobot의 고유 시리얼번호를 기준으로 현재 COM 포트를 찾아 설정을
자동 갱신합니다. 네 대를 모두 찾지 못하면 기존 설정을 변경하지 않습니다.

```powershell
python .\dobot_port_recovery.py
```

## Dobot_1 저속 조그 방향 시험

먼저 `--execute` 없이 입력값과 등록 포트만 확인합니다. 이때 로봇은 움직이지 않습니다.

```powershell
python -m manual_tests.single_robot_jog_test --axis z --direction +
python -m manual_tests.single_robot_jog_test --robot Dobot_2 --axis r --direction +
```

컨베이어 등 주변 간섭이 없고 비상정지를 사용할 준비가 된 경우에만 실제 시험을
실행합니다. 한 번의 명령은 최대 0.25초, 속도는 최대 10%로 제한되며 현재 알람이
있으면 자동으로 차단됩니다.

```powershell
python -m manual_tests.single_robot_jog_test --axis z --direction + --duration 0.10 --speed 5 --execute
```

이동 명령은 통신 오류가 발생해도 자동 재시도하지 않습니다. 시험할 때는 항상 로봇
옆에서 비상정지를 준비하고, 먼저 안전한 Z 방향부터 아주 짧게 확인하세요.

## JOG 즉시 정지 시험

조그 시작과 정지를 별도 명령으로 보내 즉시 정지 기능을 확인합니다. 정지 명령이
누락되어도 Worker의 감시 시간이 끝나면 최대 0.25초 안에 자동 정지합니다.

```powershell
python -m manual_tests.jog_immediate_stop_test
python -m manual_tests.jog_immediate_stop_test --axis r --direction + --execute
python -m manual_tests.jog_immediate_stop_test --robot Dobot_2 --axis r --direction + --execute
```

## PTP 이동과 도착 확인 시험

현재 좌표를 기준으로 한 축만 조금 이동하며, 목표 오차 범위에 3회 연속 들어온 경우에만
도착으로 판정합니다. 시험 이동량은 축별 최대 5mm 또는 R축 5도로 제한됩니다.

```powershell
python -m manual_tests.ptp_arrival_test --axis r --delta 0.5
python -m manual_tests.ptp_arrival_test --axis r --delta 0.5 --execute
python -m manual_tests.ptp_arrival_test --robot Dobot_2 --axis r --delta 0.5 --execute
```

## 큐 시작·정지·초기화 시험

이동 명령을 넣지 않은 빈 큐로 컨트롤러의 초기화, 시작, 인덱스 읽기, 정지 기능을
검사합니다. 따라서 실기 시험에서도 로봇 좌표는 변하지 않아야 합니다.

```powershell
python -m manual_tests.queue_control_test
python -m manual_tests.queue_control_test --execute
```

## 강제 즉시 정지 경로

`RobotMotionController.emergency_stop()`은 일반 명령 Queue와 분리된 Event를 통해
`DobotWorker.force_stop()`을 호출합니다. 따라서 Worker가 PTP 또는 기계적 HOME의
완료를 기다리는 중에도 최대 약 20ms 간격으로 정지 요청을 확인하여 JOG 정지,
큐 강제 정지, 남은 큐 삭제를 차례로 시도합니다. 강제 정지 경로가 실패하면 기존
JOG 정지와 일반 큐 정지도 대체 경로로 시도합니다.

이 기능은 PC 프로그램 수준의 보조 안전 기능입니다. USB 통신, Windows 또는
Dobot 컨트롤러 자체가 멈춘 상황까지 보장하지 않으므로 실제 설비의 하드웨어
비상정지 회로를 대신할 수 없습니다.

## 그리퍼·흡착컵 공통 인터페이스 시험

`robots.json`의 엔드이펙터 설정에 따라 그리퍼는 열기·닫기, 흡착컵은 ON·OFF를
시험한 뒤 제어 출력을 비활성화합니다.

```powershell
python -m manual_tests.end_effector_test --robot Dobot_1
python -m manual_tests.end_effector_test --robot Dobot_1 --execute
```

## 알람 조회·초기화

조회만 할 때는 로봇 상태를 변경하지 않습니다. `--clear`를 추가하면 조그와 큐를
먼저 정지한 뒤 알람 표시를 초기화하고, 남은 원인으로 알람이 재발하는지도 확인합니다.

```powershell
python -m manual_tests.alarm_control_test
python -m manual_tests.alarm_control_test --clear
```

## 명령 시간 제한과 오류 처리 시험

실제 이동 범위를 벗어난 PTP 목표를 보내 Worker의 안전 검사에서 거부되는지 확인한
뒤, 같은 Worker로 상태를 다시 읽어 오류가 다음 명령에 전파되지 않는지 검사합니다.

```powershell
python -m manual_tests.command_error_handling_test
```

## 티칭 포인트 관리

먼저 모든 필수 포인트가 미등록된 JSON 파일을 생성합니다. 초기화만으로 현재 로봇
좌표가 저장되지는 않습니다.

```powershell
python .\teaching_point_manager.py --init
python .\teaching_point_manager.py --list
```

작업자가 로봇을 원하는 위치로 조그한 뒤 현재 좌표를 저장할 때만 `--save`를
사용합니다. 같은 포인트를 다시 저장하면 이전 좌표가 새 좌표로 교체됩니다.

```powershell
python .\teaching_point_manager.py --capture Dobot_1 ready
python .\teaching_point_manager.py --capture Dobot_1 ready --speed 5 --save
```

GUI에서 로봇을 선택하고 JOG로 위치를 조정한 뒤 현재 좌표를 저장할 수 있습니다.
JOG 속도는 1~100%이며 버튼을 누르는 동안 연속 이동하고 놓으면 즉시 정지합니다.
정지 신호가 누락돼도 0.25초 감시 시간이 끝나면 자동 정지합니다. HOME 버튼은
두 종류입니다. `현재 위치를 사용자 READY로 저장`은 티칭 좌표를 저장하고,
`기계적 HOME 이동`은 확인창 이후 컨트롤러의 원점 복귀 절차를 실행합니다.

```powershell
python .\teaching_gui.py
```

## HOME 및 안전 이동 순서 검증

기본 HOME 경로는 `기계적 HOME → 사용자 ready` 순서입니다. 작업자가 위치를 직접
판단할 때는 HOME 없이 READY 버튼으로 공정 대기를 승인할 수 있습니다. 공정 중에는
픽업 상승 위치와 조립·반환 접근 위치를 경유하고, 끝나면 사용자 `ready`로 돌아옵니다.
Dobot_3은 `_1 → pickup`으로 진입하고 `_1 → _2` 순서로 빠져나옵니다.
그리퍼 로봇은 닫기 후 2초 동안 파지가 안정되기를 기다린 뒤 상승합니다. 배치할
때도 그리퍼를 연 뒤 2초 기다리고 엔드이펙터 제어를 해제합니다. 이 대기 중에도
프로그램 비상정지 상태를 약 50ms 간격으로 확인합니다.
Dobot_3은 흡착컵을 켠 뒤 1초 동안 흡착을 유지한 다음 픽업 위치에서 상승합니다.

기본 명령은 계획만 출력하는 DRY-RUN입니다. 실제 검증은 반드시 한 대씩 실행하며,
`--execute` 후 화면에 선택한 로봇 이름까지 다시 입력해야 움직입니다.

```powershell
python -m manual_tests.home_safety_motion_test --robot Dobot_1 --mode home
python -m manual_tests.home_safety_motion_test --robot Dobot_1 --mode home --execute
python -m manual_tests.home_safety_motion_test --robot Dobot_1 --mode cycle --destination assembly_1 --execute
```

## 모바일 티칭 웹 화면

같은 Wi-Fi/LAN의 휴대폰에서 4대 상태 확인, 단일 제어권, 직교·관절 JOG,
JOG 즉시정지, 티칭 포인트 목록 확인과 현재 실제 좌표 저장·수정을 제공합니다.
현재 단계에는 포인트 PTP 이동과 HOME 기능을 넣지 않았습니다. PC 통합 GUI·티칭
GUI와 동시에 같은 COM 포트를 사용할 수 없으므로 다른 Dobot 프로그램을 먼저
종료한 뒤 모바일 서버만 실행합니다.

```powershell
cd ./Dobot
python mobile_teaching_server.py --lan
```

PowerShell에 표시되는 `http://PC주소:8765`를 휴대폰 브라우저에 입력한다. Windows
방화벽 안내가 표시되면 공용 네트워크가 아닌 현재 사용하는 개인 네트워크만 허용한다.
휴대폰에서 로봇을 선택하고 `제어권 획득`을 누른 뒤 JOG 또는 티칭 저장을 사용합니다.
제어권은 한 화면만 가질 수 있고 휴대폰 통신이 끊기면 약 15초 뒤 자동 만료됩니다.
JOG는 버튼 생존 신호가 약 0.25초 동안 오지 않으면 Worker가 자동 정지합니다.
현재 좌표 저장은 선택 포인트, 속도 1~100%, 확인 대화상자를 거쳐 수행하며 알람이
있는 로봇은 저장을 차단합니다.

## 공정 상태 머신

`robot_control/process_state_machine.py`는 PLC 기동 신호를 로봇별 공정 실행 조건으로
변환합니다. 실제 운전에서는 KEPServerEX OPC-UA 입력을 `ProcessSignals`로 변환하고,
서버가 없는 경로 검사에서는 GUI 모의 입력을 같은 형식으로 전달합니다.

- Dobot_1: 공급 완료와 비전 OK가 모두 있어야 단일 조립
- Dobot_2: 1회이면 `assembly_1`, 2회이면 첫 작업 후 두 번째 공급을 기다려 `assembly_2`
- Dobot_3: 비전 OK와 AGV 공급 완료가 모두 있어야 조립
- Dobot_4: 제품 도착 후 Main, Lamp_a, Lamp_b, Seat_a, Seat_b 중 반환 위치 선택
- 공통 상태: 연결 해제, HOME, 대기, 두 번째 공급 대기, 운전, 일시정지, 오류

HOME 초기화가 끝나지 않은 로봇의 공정 시작은 차단하며, 실행 오류나 비상정지가
발생하면 오류 상태로 전환합니다.

## PC 모의 신호

`mock_signal_source.py`는 서버 없이 경로와 상태 전이를 검사하기 위한 입력을 메모리에서
생성합니다. 실제 설비에서는 PLC가 비전·AGV 조건을 먼저 처리하고 최종 START를 주며,
OPC-UA 입력도 같은 `ProcessSignals`를 사용하므로 공정 상태 머신을 공유합니다.

공급 완료·AGV 완료·제품 도착 신호가 계속 ON인 경우에는 공정을 한 번만 실행하며,
신호가 OFF로 복귀한 뒤 다시 ON돼야 다음 공정을 허용합니다. 비전 신호가 먼저
들어오거나 나중에 들어오는 경우처럼 입력 순서가 달라도 전체 조건이 만족되면 한 번
실행합니다. 다음 명령은 실제 로봇에 연결하지 않는 모의 시험입니다.

```powershell
python -m manual_tests.mock_signal_test
```

## 통합 운전 GUI

`integrated_gui.py`는 4대 로봇의 공정 상태, PC 모의 입력, 개별·전체 HOME,
공정 시작, 작업 초기화, GUI 비상정지와 작업 로그를 한 화면에 표시합니다.
HOME·공정 경로 검사 버튼은 실제 `RobotMotionController`와 현재 티칭 좌표를
사용하여 이동 순서와 필수 포인트를 검사하지만 Worker의 이동 함수를 호출하지 않는
DRY-RUN입니다. 따라서 실제 Dobot을 움직이지 않습니다. 화면 위쪽의
`실제 4대 연결 및 상태 읽기`는 등록된 네 COM 포트에 연결하여 현재 X/Y/Z/R 좌표와
알람만 읽으며 HOME, JOG, PTP 이동 명령은 보내지 않습니다.

```powershell
python .\integrated_gui.py
```

사용 순서는 `선택/전체 HOME 경로 검사 → 로봇별 신호 입력 → 공정 경로 검사`
입니다. 실제 장비 상태 확인은 `실제 4대 연결 및 상태 읽기 → 실제 좌표 새로고침 →
실제 4대 연결 해제` 순서로 사용할 수 있습니다. `티칭 GUI 열기`를 누르면 기존의
연속 JOG, 엔드이펙터 수동 동작, HOME, 포인트 저장·수정·이동 기능을 보조 창으로
사용할 수 있습니다. 같은 COM 포트의 중복 사용을 막기 위해 통합 상태 연결을 먼저
해제해야 티칭 창이 열립니다.

네 로봇의 실제 연결이 모두 성공하면 선택 로봇 한 대의 `실제 HOME 실행`,
`PLC READY 승인`, `실제 1사이클 실행` 버튼이 준비됩니다. 실제 이동 직전에는 간섭 확인 질문에
동의한 뒤 선택한 `Dobot_1` 같은 로봇 이름을 정확히 다시 입력해야 합니다. 실제
수동 `실제 1사이클 실행`은 최대 10%이고, PLC START 자동운전은 저장된 포인트
속도를 따르되 최대 30%입니다. 예를 들어 저장 속도가 20%면 자동운전은 20%,
40%면 자동운전은 30%로 이동합니다.
`4대 전체 동시 원점복귀`는 네 Worker에서 병렬 실행됩니다. 자동 모드에서는 네 로봇이
서로 독립적으로 각자의 PLC START를 처리하므로 동시에 공정이 시작될 수 있습니다.
로봇 간 작업영역이 겹치는 설비에서는 PLC 인터록과 실제 간섭 검증이 반드시 필요합니다.
GUI의 비상정지는 연결된 실제 Worker에도 강제 정지를 요청하지만 안전등급
하드웨어 비상정지 회로를 대체하지 않습니다.

Dobot_2의 두 번째 공급 대기와 `assembly_2`까지 통합 계층으로 검증할 때는 아래
명령을 사용합니다. 실제로 `assembly_1`과 `assembly_2` 두 사이클이 실행되므로
주변 간섭과 재료 준비를 모두 확인해야 합니다.

```powershell
python -m manual_tests.integrated_live_cycle_test --robot Dobot_2 --work-count 2 --execute
```

Dobot_4는 판별된 제품 종류에 따라 다섯 반환 위치 중 하나를 선택합니다.

```powershell
python -m manual_tests.integrated_live_cycle_test --robot Dobot_4 --product-type Main --execute
python -m manual_tests.integrated_live_cycle_test --robot Dobot_4 --product-type Lamp_a --execute
python -m manual_tests.integrated_live_cycle_test --robot Dobot_4 --product-type Lamp_b --execute
python -m manual_tests.integrated_live_cycle_test --robot Dobot_4 --product-type Seat_a --execute
python -m manual_tests.integrated_live_cycle_test --robot Dobot_4 --product-type Seat_b --execute
```

## 운전 전 최종 체크리스트

1. 네 로봇 전원, USB 허브 전원, 케이블 고정을 확인합니다.
2. `dobot_connection_test`에서 정확히 4대가 성공했는지 확인합니다.
3. COM이 달라졌으면 `dobot_port_recovery.py`를 실행합니다.
4. `dobot_identity_test`로 로봇 이름과 시리얼번호가 일치하는지 확인합니다.
5. `multi_dobot_status_test`로 좌표·관절·알람과 Worker 종료를 확인합니다.
6. 티칭 포인트가 임시값인지 최종값인지 작업자가 확인합니다.
7. 통합 GUI에서 실제 4대 연결 후 4대 동시 원점복귀를 수행합니다.
8. 각 카드가 `READY ON`, KEPServerEX 태그도 `True`인지 확인합니다.
9. 수동 모드에서 PLC START는 표시만 되고 로봇이 기동하지 않는지 확인합니다.
10. 자동 모드는 PLC·컨베이어·AGV·비전 인터록과 비상정지 준비 후 사용합니다.

자동 테스트 통과는 코드 로직의 회귀 오류가 없다는 뜻이며, 실제 좌표와 설비 간섭이
안전하다는 뜻은 아닙니다. 티칭 좌표 변경 후에는 반드시 저속으로 한 대씩 경로를 다시
검증해야 합니다. Python 비상정지는 하드웨어 안전회로를 대체하지 않습니다.

## 현재 남아 있는 운영 확인 사항

- Dobot_4 제품 종류 태그는
  `ns=2;s=M.PLC.VISION_I/O.VISION4_CLASS_RESULT`로 확정되었습니다.
- PLC ERROR 상세 코드용 데이터 레지스터는 아직 정하지 않았습니다.
- 모든 티칭 좌표는 설비 최종 배치에 따라 GUI에서 다시 조정될 수 있습니다.
- KEPServerEX가 일시적으로 끊기면 현재 신호 교환 스레드는 안전하게 종료됩니다.
  재접속 자동화는 후속 작업이며, 현재는 실제 4대 연결을 해제한 뒤 다시 연결합니다.
- 모바일 티칭은 상태·JOG·현재 좌표 저장 단계까지 구현됐습니다. 포인트 이동,
  HOME 및 공구 동작은 실제 안전 검증 후 추가할 예정이며 최종 자동운전은 PC 통합
  GUI에서 수행합니다.

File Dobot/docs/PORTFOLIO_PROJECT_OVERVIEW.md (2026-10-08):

# PLC·Vision 연동형 다중 Dobot 생산 자동화 시스템

## 프로젝트 개요

인천인력개발원 `로봇활용 첨단생산시스템 전문가 양성과정`에서 수행한 8인 팀 프로젝트입니다.
PBV 차량의 시트·램프·바디 조립 공정을 축소 구현하고, Mitsubishi PLC와 웹캠 기반
Vision 판정 결과에 따라 Dobot Magician 4대가 조립·분류·불량 회수·부품 재공급 작업을
수행하도록 구성했습니다. KEPServerEX와 OPC UA를 이용해 PLC, Robot PC, Vision,
SCADA 사이의 상태와 공정 데이터를 연결합니다.

## 담당 역할

- 팀장으로서 일정과 업무를 조율하고 장치 간 인터페이스와 통합 시운전을 지원했습니다.
- 로봇 제어를 주 담당으로 맡아 Dobot 4대 연결, 티칭, 공정 실행, 상태 관리와 오류 복구를 구현했습니다.
- PLC 관련 자격 지식을 바탕으로 래더 시퀀스, 인터록과 로봇 핸드셰이크 검증을 지원했습니다.
- Vision 알고리즘은 팀원이 담당했으며, 판정 결과가 PLC와 로봇 공정에 연결되는 조건을 검토했습니다.

## 시스템 흐름

1. SCADA가 주문 정보를 KEPServerEX 태그에 기록합니다.
2. PLC가 센서와 주문 정보를 읽고 제품을 Vision 검사 위치까지 이송합니다.
3. 웹캠은 계속 영상을 제공하며, PLC START 신호가 들어오면 Vision 판별 프로그램이 현재 영상을 검사합니다.
4. Vision이 OK·NG 결과를 KEPServerEX에 기록하고 PLC가 인터록과 후속 공정을 결정합니다.
5. Robot PC가 PLC의 START와 공정 조건을 읽어 해당 Dobot의 작업을 실행합니다.
6. Robot PC는 RUNNING·FINISH·ERROR·READY와 로봇 좌표를 PLC·SCADA에 전달합니다.

## 로봇 제어 핵심 설계

### 개별 오류 격리

각 Dobot은 독립 Worker 프로세스와 명령 대기열을 사용합니다. 한 로봇의 통신 지연이나
오류가 발생해도 다른 로봇의 상태 조회와 제어를 계속할 수 있습니다.

### 안전 정지

알람, 시간초과 또는 좌표 미변화를 감지하면 해당 로봇의 JOG와 이동 큐를 정지하고
남은 명령을 삭제합니다. 실행 여부를 확신할 수 없는 이동 명령은 자동으로 재전송하지 않습니다.

### 제한적 자동복구

PING, 장치 정보, 상태 조회처럼 실제 움직임이 없는 명령만 Worker 재시작 후 한 번 재시도합니다.
PTP, JOG, HOME과 엔드이펙터 명령은 중복 동작을 방지하기 위해 자동 재실행하지 않습니다.

### 검증 후 재가동

오류 원인을 제거하고 해당 로봇의 HOME과 사용자 READY 위치 복귀가 성공한 경우에만
PLC ERROR를 해제하고 READY 상태로 전환합니다. 필수 티칭 포인트가 없으면 자동운전을 차단합니다.

## PLC 핸드셰이크

| 신호 | 방향 | 의미 |
|---|---|---|
| START | PLC → Robot PC | 공정 시작 요청 |
| RUNNING | Robot PC → PLC | 로봇 작업 중 |
| FINISH | Robot PC → PLC | 공정 완료 |
| ERROR | Robot PC → PLC | 오류 발생 |
| READY | Robot PC → PLC | 다음 공정 실행 가능 |

START는 상승 에지에서 한 번만 처리합니다. FINISH는 완료 시점부터 약 1초간 유지하고,
실행 중 들어온 다음 START는 로봇별로 최대 한 건만 예약하여 중복 기동을 방지합니다.

## 주요 문제 해결

- COM 포트가 변경되어도 저장된 시리얼번호로 동일한 Dobot을 찾아 설정을 복구합니다.
- 로봇별 독립 Worker로 한 대의 응답 지연이 전체 제어에 전파되는 것을 막습니다.
- START의 변화 시점을 구분하여 신호가 계속 ON인 경우의 반복 기동을 방지합니다.
- 통신 단절 시 오래된 좌표를 다시 전송하지 않고, 제어와 좌표 전송의 장애 영향을 분리합니다.

## 검증 방법

- `tests/`: 실제 장비 없이 상태 전이, 통신 계약, 티칭 경로와 오류 처리를 검증하는 자동시험
- `manual_tests/`: 실제 Dobot의 연결, 식별, JOG, PTP, HOME과 통합 공정을 단계별로 확인하는 시험
- 실제 이동 시험은 저속으로 수행하며, 주변 간섭과 비상정지 준비를 확인한 뒤 `--execute` 옵션을 사용합니다.

자동시험 결과와 실제 장비 시험 결과는 구분하여 기록합니다. 실제 설비의 안전성, 정확도와
반복성은 최종 티칭, PLC 래더 검증, Vision 조건별 시험과 전체 연속운전 결과로 확인합니다.

## AI 활용 개발 방식

AI 기반 바이브 코딩을 반복 코드 작성, 오류 원인 분석, 구조 개선과 주석 작성에 활용했습니다.
로봇별 독립 Worker, 상태 머신, PLC 핸드셰이크와 오류 복구 조건은 실제 공정 요구사항을 바탕으로
직접 정의했습니다. 생성된 코드는 동작 원리를 검토하고 자동시험과 실제 Dobot 통신 시험을 통해
검증한 뒤 적용했습니다.

## 관련 문서

- [프로젝트 실행 및 시험 안내](../README.md)
- [OPC UA 사용 안내](OPCUA_README.md)
- [로봇 OPC UA 태그 목록](ROBOT_OPCUA_TAGS.md)
- [코드 분석 및 개선 제안](Dobot_코드_분석_및_개선제안.md)

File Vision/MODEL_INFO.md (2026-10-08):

# 모델 파일 대조 결과

V13.29 폴더의 vision1_best.pt, vision2_best.pt, vision3_best.pt, vision4_best.pt는 SHA256이 모두 같으며 사용자가 실제 사용 모델로 지정한 train-v15-best/weights/best.pt와도 동일합니다.

SHA256: `1e26e2513a894c812bbf188bbfd827bc9304640054e87c708b6d75b832ee4576`

원본 MODEL_APPLIED.txt의 기록: 사용자 제공 best(2).pt, detect, 클래스 car body / car lamp_A / car lamp_R / car seat. 이 모델 자체는 시트 색상 종류를 구분하지 않으며 V2·V4의 색상 처리는 Python/OpenCV가 보완합니다. 최신 V3의 시트 유무는 ROI 픽셀 비율을 사용합니다.

모델의 동일성은 해시로 확인했습니다. 가중치 추론 성능과 현장 적용 결과를 이번 작업에서 재검증한 것은 아닙니다. 모델 바이너리는 이번 공개본에서 제외합니다. 과거 models/README_KO.txt의 V1/V2 역할이 뒤바뀐 안내는 그대로 복사하지 않았습니다.

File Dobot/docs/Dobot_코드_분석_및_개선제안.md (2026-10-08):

# Dobot 프로젝트 코드 분석 및 개선 제안

대상: `DobotControl_Main`, `DobotControl_Test` (2026-09-10 기준 코드)

전체적으로 `DobotControl_Main`은 안전장치(속도·이동거리 제한, JOG watchdog, 프로세스 격리, 원자적 파일 저장, 입력 검증 dataclass 등)가 매우 꼼꼼하게 설계되어 있습니다. 반면 `DobotControl_Test`는 초기 프로토타입 성격이 강하고, Main에서 이미 해결된 안전 문제들이 그대로 남아 있습니다. 아래는 실제로 발견한 버그와 개선 여지를 우선순위별로 정리한 것입니다.

---

## 1. 실제 버그 (동작 오류로 이어짐)

### 1-1. `DobotControl_Test/robot.py` — `is_connected` 속성이 초기화되지 않음 (크래시 위험)
`DobotRobot.__init__`에는 `self.is_connected = True`를 설정하는 코드가 없습니다. 그런데 `disconnect()`의 첫 줄은 다음과 같습니다.

```python
def disconnect(self):
    if not self.is_connected:   # <-- 존재하지 않는 속성 참조
        return
```

`DobotRobot` 인스턴스를 만든 뒤 `disconnect()`를 처음 호출하면 `AttributeError: 'DobotRobot' object has no attribute 'is_connected'`가 발생합니다. 문제는 이 오류가 나면 `dType.DisconnectDobot(self.api)`가 아예 실행되지 않아 **COM 포트가 계속 점유된 상태로 남는다**는 점입니다. `main.py`의 예외 처리 블록, `gui.py`의 `_finish_disconnect()`, 그리고 `gripper_test.py`/`suction_test.py`의 `finally: robot.disconnect()`가 모두 이 경로를 타므로, 프로그램이 예외로 종료될 때마다 포트가 풀리지 않을 가능성이 높습니다.

**수정 제안**: `__init__` 끝에 `self.is_connected = True`를 추가하고, 연결 실패 시 예외를 던지기 전에는 설정하지 않도록 합니다.

### 1-2. `DobotControl_Main/dobot_ptp.py` — 오류 메시지가 실제 허용 범위와 다름
```python
MIN_TIMEOUT = 1.0
MAX_TIMEOUT = 120.0
...
if not MIN_TIMEOUT <= timeout <= MAX_TIMEOUT:
    raise ValueError("PTP 도착 대기시간은 1~15초여야 합니다.")
```
상수는 1~120초인데 오류 메시지는 "1~15초"로 되어 있습니다. 예전 버전에서 남은 문구로 보입니다. `robot_control/robot_motion_controller.py`와 `teaching/teaching_gui.py`는 실제로 90초 타임아웃을 사용하므로 이 메시지를 본 사용자는 "90초는 왜 되지?"라며 혼란스러울 수 있고, 반대로 실제 한도(120초)를 15초로 오인해 불필요하게 값을 낮출 수도 있습니다. `tests/test_dobot_ptp.py`에도 이 경계값(120초 초과)을 검증하는 테스트가 없어서 지금까지 잡히지 않은 것으로 보입니다.

**수정 제안**: 메시지를 `f"PTP 도착 대기시간은 {MIN_TIMEOUT:.0f}~{MAX_TIMEOUT:.0f}초여야 합니다."`처럼 상수를 참조하도록 바꾸고, 경계값 테스트를 하나 추가하면 이런 종류의 드리프트를 앞으로 방지할 수 있습니다.

### 1-3. `DobotControl_Test/gui.py` — 포트 하드코딩 불일치
`main.py`는 `DobotRobot(port="COM5", ...)`로 연결하는데, `gui.py`의 `connect_robot()`(로봇 없이 GUI만 실행되거나 "재연결" 버튼을 눌렀을 때 호출됨)은 다음처럼 포트가 다르게 하드코딩되어 있습니다.
```python
self.robot = DobotRobot(port="COM3", baudrate=115200)
```
재연결 시 실제로 연결하려는 로봇과 다른 COM 포트를 시도하게 되어, 포트가 COM5인 환경에서는 "재연결" 버튼이 항상 실패하거나(최악의 경우 다른 장치가 COM3에 물려 있다면 엉뚱한 장치에 연결) 예기치 않은 동작을 일으킵니다.

**수정 제안**: `Main` 프로젝트처럼 포트를 설정 파일이나 생성자 인자로 넘겨 GUI가 하드코딩된 값을 갖지 않도록 하는 것이 근본적인 해결책입니다.

### 1-4. `DobotControl_Test/gripper_test.py`, `gripper_immediate_test.py` — 생성 실패 시 `NameError`로 원인 오류가 가려짐
```python
robot = DobotRobot()
try:
    ...
finally:
    robot.disconnect()
```
`DobotRobot()` 생성자 자체가 실패하면(포트 연결 실패 등) `robot` 변수가 만들어지지 않은 채 `finally`에서 `robot.disconnect()`를 호출하려다 `NameError`가 발생합니다. 진짜 원인(연결 실패)이 `NameError`에 가려져 디버깅이 어려워집니다. `suction_test.py`는 `robot = None`으로 먼저 초기화하고 `if robot is not None:`으로 방어하고 있으니 같은 패턴을 적용하면 됩니다.

---

## 2. 설계·안전 관점 개선 제안

### 2-1. `DobotControl_Test`에는 JOG 정지 실패에 대한 안전망(watchdog)이 없음
`Main`의 `dobot_worker.py`는 JOG 시작 후 정지 명령이 오지 않아도 0.25초 안에 자동으로 멈추는 watchdog(`jog_deadline`)을 갖고 있습니다. 반면 `Test`의 `gui.py`는 버튼의 `<ButtonRelease-1>`/`<Leave>` 이벤트에만 의존합니다. 창이 포커스를 잃거나(Alt-Tab), 이벤트가 드물게 유실되는 경우 로봇이 정지 명령 없이 계속 움직일 수 있습니다. 이미 `Main`에 구현되어 검증된 watchdog 패턴을 `Test`에도 이식하거나, `Test` 프로젝트를 더 이상 실제 로봇 구동에 쓰지 않도록 정리하는 것을 권장합니다.

### 2-2. `DobotControl_Test/robot.py`의 `home()`에 좌표가 하드코딩됨
```python
home_x = 213.0  #Dobot_1 : 200.0, Dobot_2 :163.0
home_y = 3.0    #Dobot_1 : -20.0, Dobot_2 : -122.0
```
로봇마다 다른 HOME 좌표를 주석으로만 남겨두고 실제 코드는 하나의 좌표만 사용합니다. 다른 로봇에 이 코드를 재사용하면 잘못된 HOME 위치로 이동할 위험이 있습니다. `Main`은 이미 `teaching_points.json` 기반으로 로봇별 좌표를 분리했으니, `Test`를 계속 쓴다면 같은 방식으로 옮기는 것이 안전합니다.

### 2-3. `DobotWorker.move_ptp`의 타임아웃 여유값이 상한 근처에서 어긋날 수 있음 (`dobot_worker.py`)
```python
return self.request(CommandName.MOVE_PTP, arrival_timeout + 2.0, payload)
```
`PTPRequest`는 `timeout`(=`arrival_timeout`)을 최대 120초까지 허용하지만, `request()`가 호출하는 `validate_timeout()`은 최대 120초까지만 허용합니다. `arrival_timeout`이 118~120초 사이면 `arrival_timeout + 2.0`이 120을 넘어 `ValueError`가 발생합니다. 지금은 실제 호출부(`robot_control/robot_motion_controller.py`, `teaching/teaching_gui.py`)가 90초만 쓰므로 실무에서 문제가 되지는 않지만, 이후 타임아웃 값을 늘릴 때 함정이 될 수 있는 경계 불일치입니다. `validate_timeout`의 상한을 조금 늘리거나, `move_ptp`가 여유값을 더한 뒤 클램프하도록 명시하면 좋습니다.

### 2-4. 그리퍼/흡착컵 미장착 오류 가능성
`robot_control/dobot_end_effector.py`의 `EndEffectorRequest`는 `tool_type`이 로봇에 실제로 장착된 종류(`robots.json`의 `end_effector`)와 일치하는지 검사하지 않습니다. `Worker.set_end_effector`를 호출하는 코드(`teaching/teaching_gui.py`, `robot_control/robot_motion_controller.py`)는 항상 `self.config["robots"][...]["end_effector"]`를 조회해서 쓰므로 실사용 경로에서는 문제가 없지만, 이 계층을 우회해서 직접 `worker.set_end_effector("suction", "on")`처럼 실제 장착과 다른 tool_type을 호출하면 SDK가 예기치 않게 응답할 수 있습니다. `Worker` 계층에서 로봇 설정의 `end_effector`와 비교해 한 번 더 막아주면 더 안전합니다.

---

## 3. 유지보수/코드 정리 제안

- **`DobotControl_Test`의 위치**: README를 보면 `Main`이 `Test` 폴더의 SDK 파일(`DobotDllType.py`, `DobotDll.dll`)을 그대로 가져다 쓰는 구조입니다. 즉 `Test`는 이제 "SDK 보관소 + 실험용 스크립트" 역할만 남은 것으로 보입니다. `Test`의 `robot.py`/`gui.py`는 위에서 언급한 안전 문제들을 안고 있으므로, 실제 생산 라인에서는 쓰지 않는 것이 좋고, 필요하다면 SDK만 별도 폴더(`sdk/`)로 분리해 `Main`과 공유하고 `Test`의 나머지 스크립트는 정리하는 것을 권장합니다.
- **`test.py`(Test 폴더)**: 로봇과 무관한 `input()` 연습 스크립트로 보입니다. 저장소에서 제거해도 될 것 같습니다.
- **`robot.py` 상단의 모듈 임포트 시 디버그 출력**:
  ```python
  print("실제로 불러온 DobotDllType 경로:")
  print(dType.__file__)
  print("SetPTPCmd 존재 여부:")
  print(hasattr(dType, "SetPTPCmd"))
  ```
  이 코드는 `robot.py`를 **import만 해도** 실행됩니다(`gui.py`, `main.py` 등 어디서든). 디버깅용으로 넣어둔 것이라면 `if __name__ == "__main__":` 안으로 옮기거나 로깅 레벨로 감싸는 것이 좋습니다.
- **`__pycache__` 폴더**: 두 프로젝트 모두 `__pycache__`가 소스와 같은 폴더에 남아 있습니다. 실제 운용에는 문제없지만 백업/버전 비교 시 불필요한 잡음이 됩니다. `.gitignore` 또는 백업 스크립트에서 제외 목록에 추가하는 것을 권장합니다(현재 저장소가 git으로 관리되고 있는지 확인이 필요합니다 — 버전관리가 아직 없다면 이 정도 규모의 안전-크리티컬 코드베이스는 git 도입을 강력히 추천합니다).
- **로그 폴더 정리**: `DobotControl_Main/logs`에 연결 점검 로그가 계속 쌓이고 있습니다(9월 초부터 다수). 자동 정리(예: 30일 이상 로그 삭제) 스크립트를 하나 추가하면 디스크 관리에 도움이 됩니다.

---

## 4. 잘 되어 있는 부분 (참고용)

- `dobot_worker.py`의 프로세스 격리 설계(로봇 1대당 독립 프로세스, SDK 전역 상태 충돌 회피)와 `dobot_fleet.py`의 로봇별 `try/except` 격리는 4대 동시 운용 환경에 적합한 견고한 구조입니다.
- `robot_control/dobot_config.py`/`teaching/teaching_points.py`의 "임시 파일 작성 후 교체(`.tmp` → `replace`)" 방식은 설정 파일 저장 중 정전/충돌에도 파일이 손상되지 않도록 하는 좋은 습관입니다.
- `JogRequest`/`PTPRequest` 같은 dataclass 기반 입력 검증과, 이동 전 알람 확인 → 이동 → 도착 확인(3회 연속) 패턴은 산업용 로봇 제어에 필요한 안전 검증을 잘 반영하고 있습니다.
- 각 스크립트가 `--execute` 플래그 없이는 DRY-RUN만 하도록 만든 CLI 설계는 현장 오조작을 막는 데 실질적으로 도움이 됩니다.

---

## 요약 우선순위

| 우선순위 | 항목 | 파일 |
|---|---|---|
| 높음 | `is_connected` 미초기화로 disconnect 시 크래시·포트 미해제 | `DobotControl_Test/robot.py` |
| 높음 | 재연결 시 COM 포트 하드코딩 불일치(COM3 vs COM5) | `DobotControl_Test/gui.py` |
| 중간 | PTP 타임아웃 오류 메시지가 실제 범위(120초)와 다름(15초로 표시) | `DobotControl_Main/dobot_ptp.py` |
| 중간 | 생성자 실패 시 `NameError`로 원인 오류가 가려짐 | `DobotControl_Test/gripper_test.py`, `gripper_immediate_test.py` |
| 중간 | JOG watchdog 부재 (버튼 이벤트 유실 시 무한 이동 가능) | `DobotControl_Test/gui.py` |
| 낮음 | HOME 좌표 하드코딩 | `DobotControl_Test/robot.py` |
| 낮음 | move_ptp 타임아웃 경계 불일치(118~120초 구간) | `DobotControl_Main/dobot_worker.py` |
| 낮음 | import 시점 디버그 출력, 미사용 test.py, `__pycache__` 정리 | `DobotControl_Test` 전반 |

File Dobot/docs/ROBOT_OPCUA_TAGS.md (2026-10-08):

# Dobot OPC UA 신호 목록

서버: `opc.tcp://127.0.0.1:49320`

그룹: `ns=2;s=M.PLC.ROBOT_I/O`

운전 신호는 `communication/robot_opcua_tags.py`, 좌표 태그는
`communication/robot_position_opc.py`에서 관리합니다.
아래 `(n)`은 `(1)`~`(4)`이며 각각 Dobot_1~Dobot_4에 대응합니다.

Dobot_4 차량 하부 출고 전용 태그:

- `ns=2;s=M.PLC.ROBOT_I/O.ROBOT_START(B)_(4)`: PLC → Python 베이스 공급 시작
- `ns=2;s=M.PLC.ROBOT_I/O.ROBOT_FINISH(B)_(4)`: Python → PLC 베이스 공급 완료 펄스

| 태그 이름 | 자료형 | 전달 방향 | 의미 |
|---|---|---|---|
| ROBOT_START_(n) | Boolean | PLC → Python | 해당 Dobot 기동 명령 |
| ROBOT_ERROR_(n) | Boolean | Python → PLC/SCADA | 해당 Dobot 오류 |
| ROBOT_FINISH_(n) | Boolean | Python → PLC/SCADA | 공정 완료 후 대기 위치 도착 |
| ROBOT_READY_(n) | Boolean | Python → PLC/SCADA | 대기 위치에서 다음 공정 준비 완료 |
| ROBOT_RUNNING_(n) | Boolean | Python → PLC/SCADA | 해당 Dobot 공정 실행 중 |
| ROBOT_Program_NO_(2) | UInt16 | PLC → Python | Dobot_2의 1회/2회 공정 선택 |
| ROBOT2_TARGET_COUNT | UInt16 | PLC → Python | Dobot_2 목표 공정 횟수 |
| ROBOT2_FINISH_COUNT | UInt16 | PLC → Python | PLC가 증가 및 초기화하는 Dobot_2 완료 횟수 |

## SCADA 좌표 태그

통합 GUI에서 실제 로봇 4대 연결에 성공하면 Python이 아래 Float 좌표를 약 1초마다
KEPServerEX에 기록하고 SCADA는 같은 태그를 읽습니다.

| 범위 | 자료형 | 전달 방향 | 의미 |
|---|---|---|---|
| `Coord.ROBOT1_X` ~ `Coord.ROBOT4_J4` | Float | Python → KEPServerEX → SCADA | 4대의 X/Y/Z/R/J1/J2/J3/J4 |

정확한 NodeId 형식은
`ns=2;s=M.PLC.ROBOT_I/O.Coord.ROBOT{번호}_{축}`입니다. 총 32개이며, 좌표는
새 COM 연결이 아니라 기존 Dobot Worker가 읽은 실제 `GetPose` 값을 사용합니다.

NodeId는 그룹 뒤에 `.`과 태그 이름을 붙인 값입니다. 대소문자를 그대로 유지합니다.

## 기존 코드 연결

`node_map_for_robot("Dobot_1")`은 기존 논리 신호인 `command.start`,
`status.busy`, `status.done`, `status.error`, `status.ready`를 실제 NodeId에 연결합니다.
이를 `OpcUaBackend(node_map=...)`에 전달할 수 있습니다.

Dobot_2의 프로그램 번호, 목표 횟수, 완료 횟수는 별도 신호로 등록했습니다.
자동 기동은 프로그램 번호를 사용하지 않고 목표 횟수와 완료 횟수만 검사합니다.
자동 모드는 목표 횟수를 `work_count`, 완료 횟수를 `completed_count`로 전달합니다.
기존 `communication/plc_io_map.py`의 M/D 주소와 실제 태그 간 대응도 이번 정보만으로 추정하지 않습니다.

## 확정된 Dobot_2 횟수 규칙

- PLC가 `ROBOT2_TARGET_COUNT`를 1 또는 2로 설정합니다.
- `ROBOT_FINISH_(2)=True`이고 `ROBOT2_TARGET_COUNT == ROBOT2_FINISH_COUNT`이면
  PLC가 `ROBOT2_FINISH_COUNT`와 `ROBOT2_TARGET_COUNT`를 모두 0으로 초기화합니다.
- 따라서 목표가 1이면 1회 완료 후, 목표가 2이면 2회 완료 후 위 조건으로 초기화합니다.
- PLC가 각 조립의 FINISH를 확인하고 완료 횟수를 1씩 증가시킵니다.
- Python은 완료 횟수와 목표 횟수를 읽기만 합니다.
- START 한 번에는 seat 하나만 조립합니다. 2회 프로그램도 두 번째 PLC START를 기다립니다.
- Program_NO 자체를 초기화하는 규칙은 지정되지 않았습니다.

### Program_NO=2일 때 순서

| 단계 | PLC 동작 | Dobot_2 동작 |
|---|---|---|
| 1 | TARGET_COUNT=2, 첫 seat 공급 후 첫 START | assembly_1 조립, 대기 위치 복귀 후 FINISH |
| 2 | FINISH_COUNT=1, 두 번째 seat 공급 후 다음 START | assembly_2 조립, 대기 위치 복귀 후 FINISH |
| 3 | FINISH_COUNT=2, 목표와 같으므로 FINISH_COUNT와 TARGET_COUNT를 0으로 초기화 | 다음 배치 기동 대기 |

실행 연동 시 START를 수락한 시점의 완료 횟수 0/1로 assembly_1/assembly_2를
선택하고, 실행 중 PLC의 카운터 갱신으로 조립 위치를 바꾸지 않아야 합니다.
자동 모드는 PLC 완료 횟수로 목적지를 선택하며 기존 수동 모드의 공정 순서는 유지합니다.

일반 FINISH와 Dobot_4 베이스 공급 FINISH는 각각 OPC-UA에 처음 ON을 기록한 뒤
약 1초 동안 유지합니다. ERROR는 작업자 초기화 후 READY를 다시 승인하면 해제됩니다.

통합 화면의 자동 모드를 선택하면 실제 PLC 응답 쓰기와 로봇 기동이 활성화됩니다.
개발 검증 과정에서는 실제 자동 기동이나 PLC 쓰기를 실행하지 않았습니다.
조회 시 Bad/None인 값을 정상 명령 또는 0으로 사용하면 안 됩니다.

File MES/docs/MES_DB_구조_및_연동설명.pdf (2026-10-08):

# 최신값·이력·제품 기록의 분리

MySQL opcua-manufacturing | 원본 운영 데이터 제외, 구조만 제공
TEAM 2 | SCADA · MES | 공개용 자료 | 2026-10-08 | 1

## 설비 태그: 최신값 + 변경 이력

team2-robotdb / team2-vision / team2-order / team2-plcstatus

각 테이블의 -history에 변경값 저장. 태그 ID·값·품질·원본/서버/수신 시각·모드 보존

SQLite 임시 저장 및 UUID로 재전송 중복 방지. 과거 이력 재전송이 최신값을 되돌리지 않도록 처리

## MES 업무 기록: 12개 테이블

mes_orders / mes_units / mes_events: 주문·제품·작업자 확인 이벤트

mes_inventory / mes_approvals / mes_reports / mes_feedback: 재고·승인·보고서·피드백

mes_dispatch_queue / mes_scada_outbox / mes_erp_outbox: 대기열과 전송 대기

mes_external_orders / mes_external_production: 원본 주문·생산 이력과 MES 매핑

공개용 초기 재고는 0. 실제 재고·사용자·생산 이력 및 기존 보고서는 포함하지 않습니다.

# SCADA 읽기 연동과 남은 구현

원본 DB를 읽고 MES DB에 저장하는 구조

TEAM 2 | SCADA · MES | 공개용 자료 | 2026-10-08 | 2

원본 smart_factory: orders + product_master + production_history, 약 3초 주기 읽기

(source_name, source_order_id) 식별자로 중복 등록 방지. 제품 코드와 PLC 프로그램 번호를 구분

기존 주문은 TEST, 신규 주문은 최초 등록 시 GUI 모드 사용. 모드 변경으로 기존 주문 재생성하지 않음

원본 시각은 Asia/Seoul 기준 해석 후 UTC로 저장, 화면은 한국 시간 표시

과거 완료 주문에 중간 작업·승인·재고 이력을 꾸며 넣지 않음. 수동 MES 기록을 원본 동기화로 덮어쓰지 않음

재생산 큐와 ERP outbox는 저장되지만 실제 SCADA 명령 쓰기/ACK 및 ERP 전송은 미연결

기존 문서의 미연결 설명 뒤에 읽기 연동 갱신이 추가돼 있음. 읽기 구현과 쓰기 미연결을 구분

검증 범위: 코드 구문·설정 구조·비공개 값 검사·PDF 화면 확인. MySQL/PLC/OPC UA 서비스와 연결해 실행하지 않았습니다.

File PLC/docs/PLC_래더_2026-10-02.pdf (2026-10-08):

Program setting | 10/2/2026

## Data Name : Program setting

Execution type | Program file name [Title] | Local device comment
Initial Program | - | -
Scan Program | 9__SERVO | None
| 7__RE | None
| 6__VI | None
| 5__ROBOT | None
| 4__SEAT | None
| 3__LAMP | None
| 2__BODY | None
| 1__MAIN | None
| 10__MANU | None
| 8__V_4 | None
Standby Program | - | -
Fixed Scan Program | - | -
No Execution Type | - | -

1

Ladder | 10/2/2026

# Data Name : 10__MANU

2

Ladder | 10/2/2026

# Data Name : 10__MANU

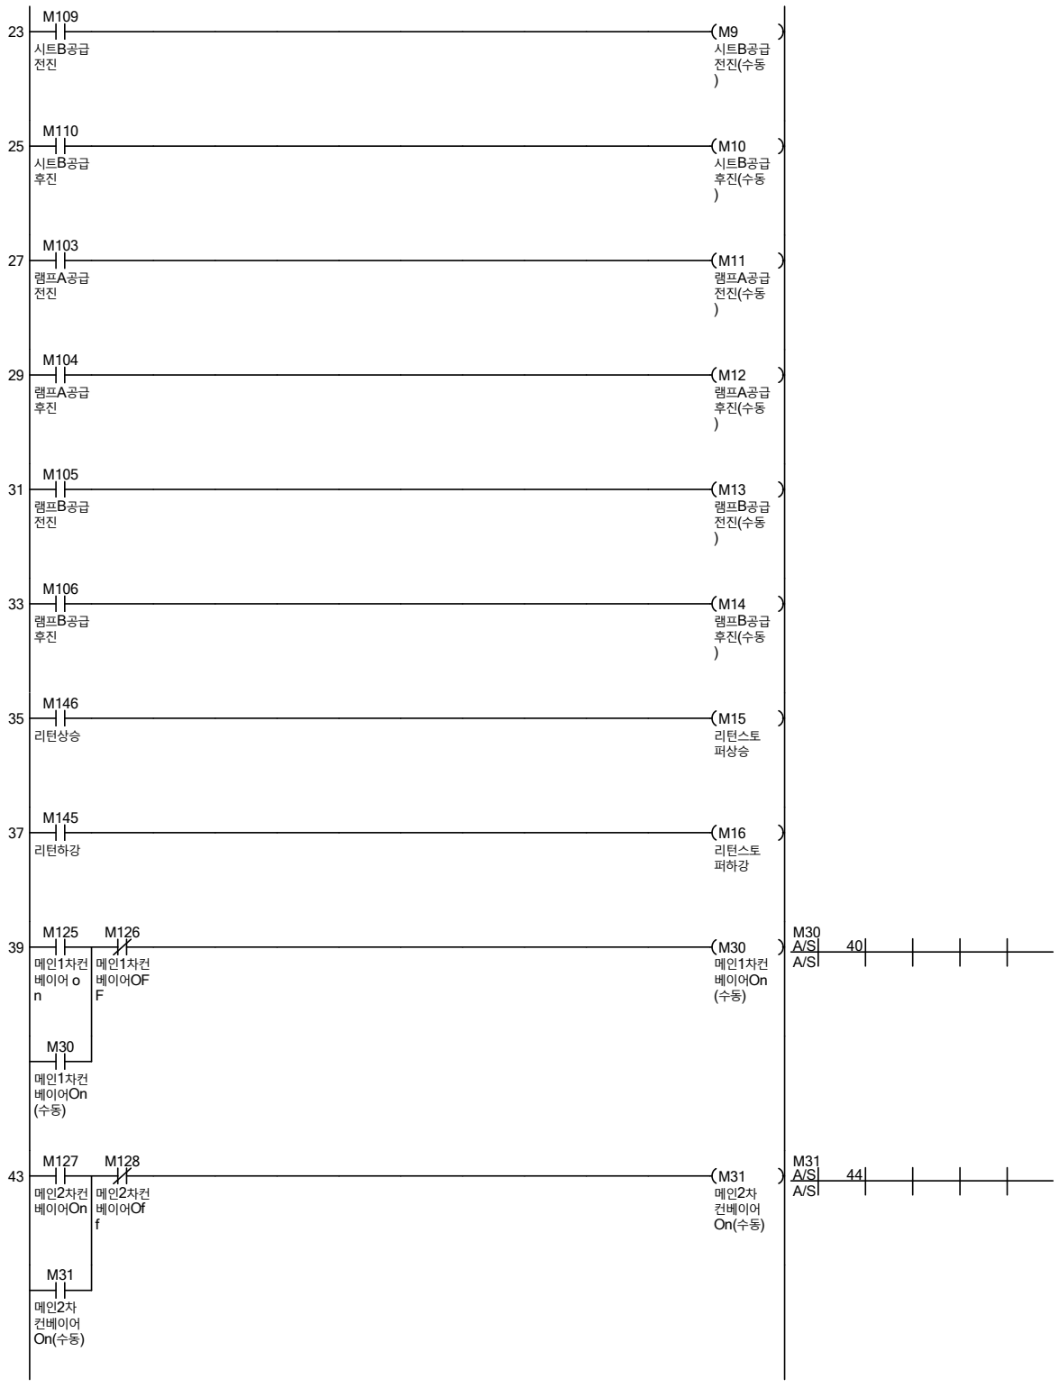
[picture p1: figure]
리턴상승; M15 리턴스토 퍼상승; 리턴하강; M16 리턴스토 퍼하강; 메인 차컨 1 베이어 o n; 메인 차컨 1 베이어OF F; M30 메인 차컨 1 베이어On; 메인 차컨 1 베이어On; 메인 차컨 2 베이어On; 메인 차컨 2 베이어Of f; M31 메인 차2 컨베이어; 메인 차2 컨베이어

3

Ladder | 10/2/2026

# Data Name : 10__MANU

4

Ladder | 10/2/2026

# Data Name : 10__MANU

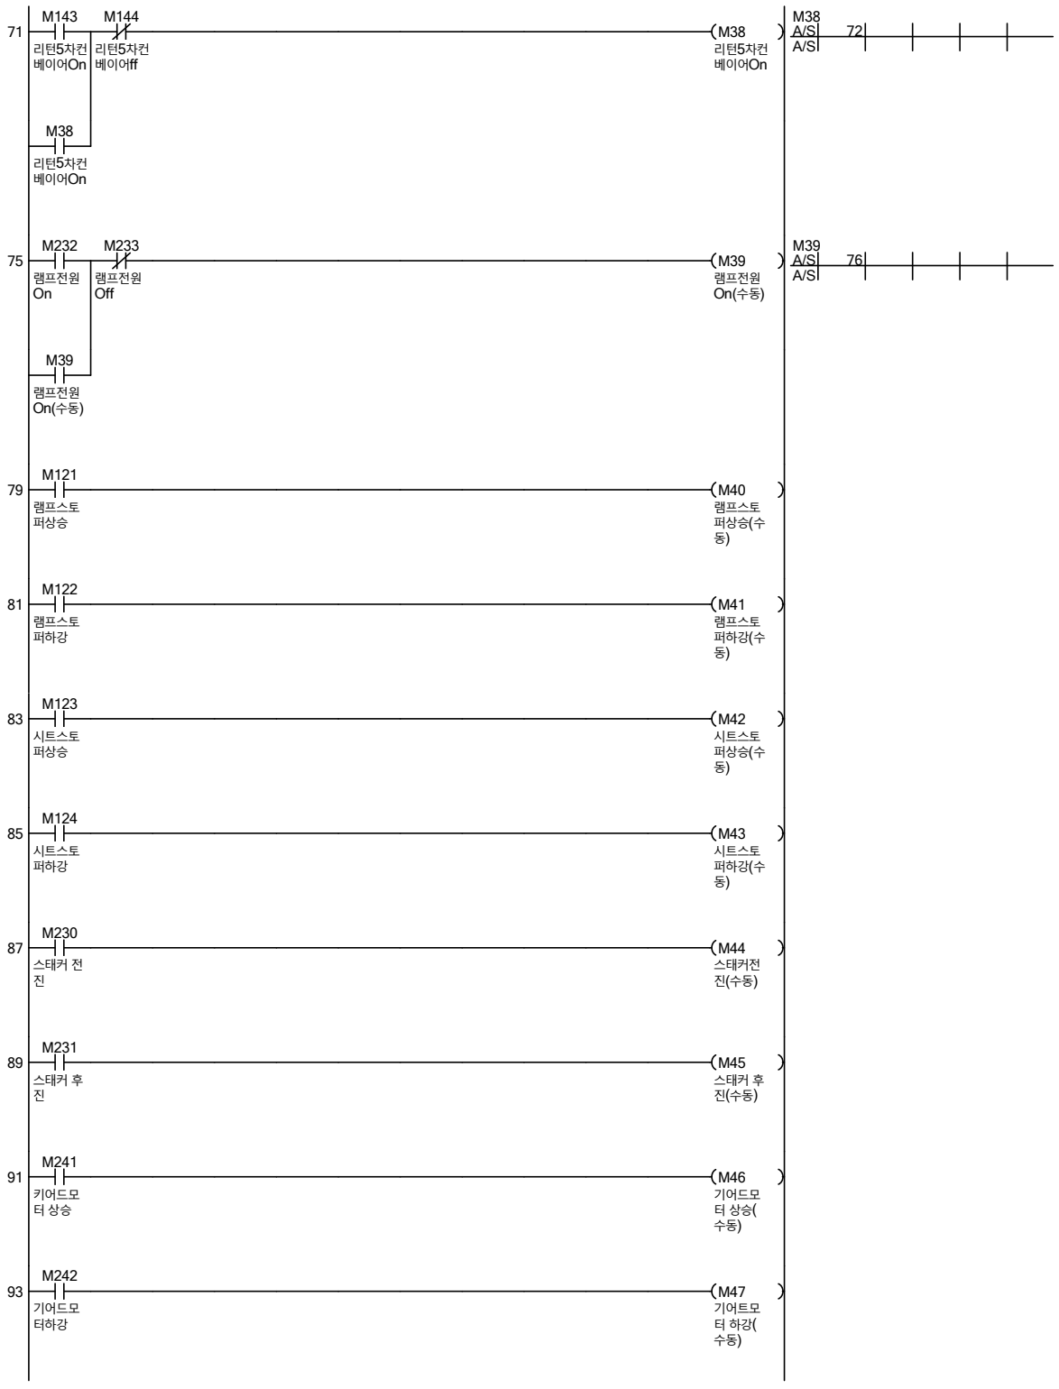
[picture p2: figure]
리턴 차컨 5 베이어On; 리턴 차컨 5 베이어ff; M38 리턴 차컨 5 베이어On; 램프전원 On; 램프전원 Off; M39 램프전원; 램프전원; 램프스토 퍼상승; M40 램프스토 퍼상승 수( 동); 램프스토 퍼하강; M41 램프스토 퍼하강 수( 동); 시트스토 퍼상승; M42 시트스토 퍼상승 수( 동); 시트스토 퍼하강; M43 시트스토 퍼하강 수( 동); 스태커 전 진; M44 스태커전; 스태커 후 진; M45 스태커 후; 키어드모 터 상승; M46 기어드모 터 상승 ( 수동); 기어드모 터하강; M47 기어트모 터 하강 ( 수동)

5

Ladder | 10/2/2026

# Data Name : 10__MANU

6

Ladder | 10/2/2026

# Data Name : 1__MAIN

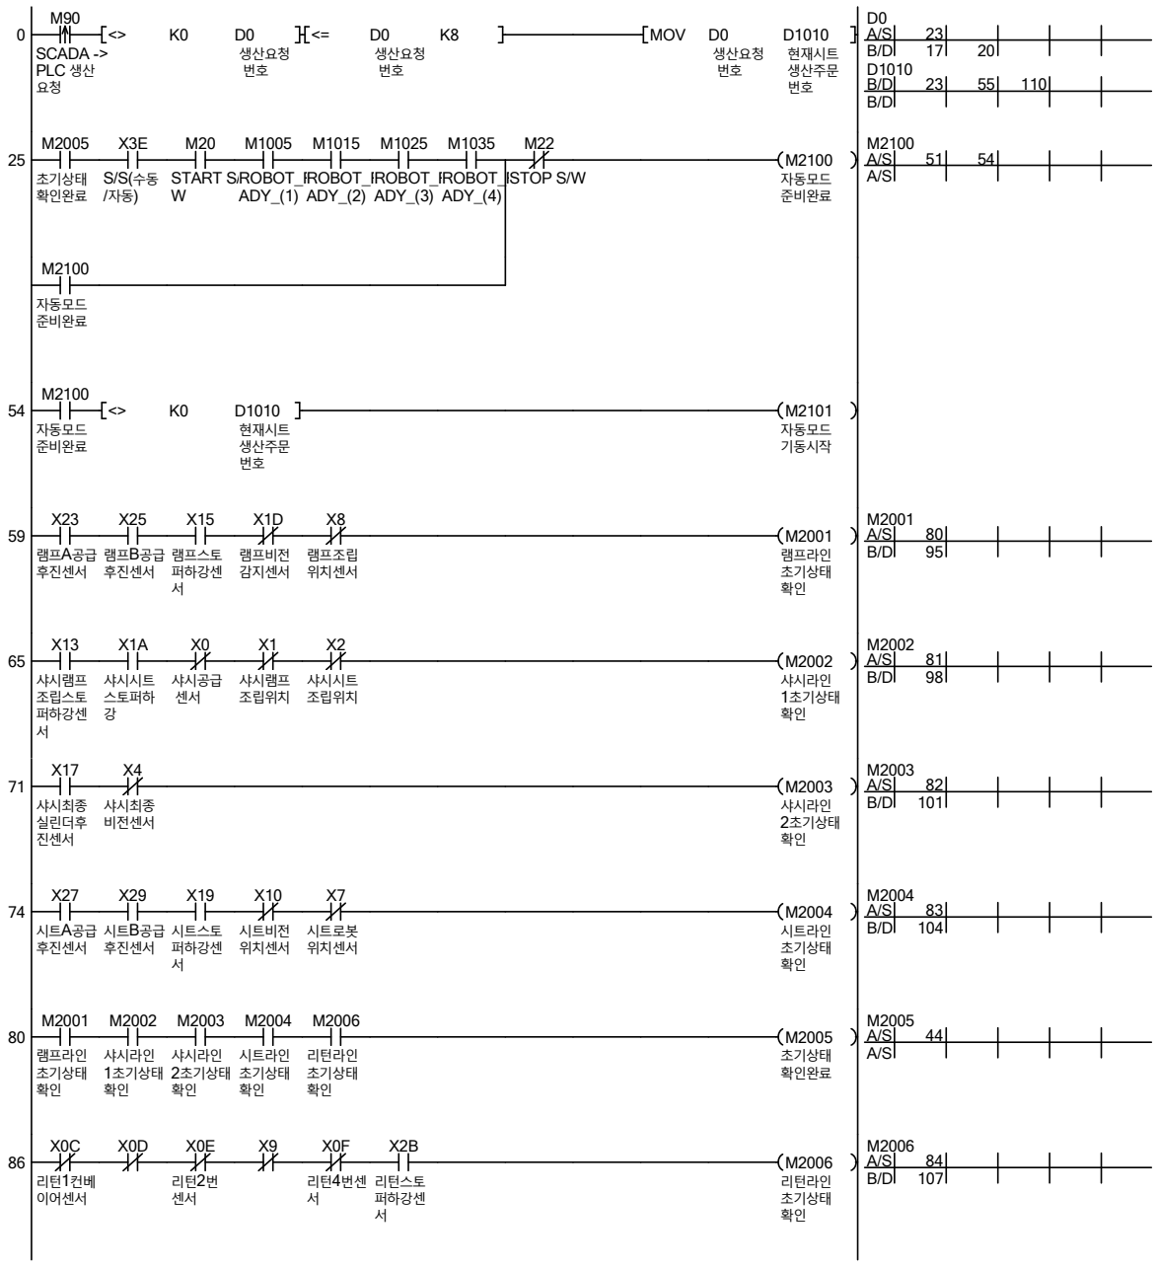
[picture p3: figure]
SCADA -> PLC 생산 요청; 생산요청 번호; MOV; D1010 현재시트 생산주문 번호; 초기상태 확인완료; START S/ W; ROBOT_RE ADY_(1); ROBOT_RE ADY_(2); ROBOT_RE ADY_(3); ROBOT_RE ADY_(4); STOP S/W; M2100 자동모드 준비완료; 자동모드 준비완료; 현재시트 생산주문 번호; M2101 자동모드 기동시작; 램프 공급 A 후진센서; 램프 공급 B 후진센서; 램프스토 퍼하강센 서; 램프비전 감지센서; 램프조립 위치센서; M2001 램프라인 초기상태 확인; 샤시램프 조립스토 퍼하강센 서; 샤시시트 스토퍼하 강; 샤시공급 센서; 샤시램프 조립위치; 샤시시트 조립위치; M2002 샤시라인 1초기상태 확인; 샤시최종 실린더후 진센서; 샤시최종 비전센서; M2003 샤시라인 2초기상태 확인; 시트 공급 A 후진센서; 시트 공급 B 후진센서; 시트스토 퍼하강센 서; 시트비전 위치센서; 시트로봇 위치센서; M2004 시트라인 초기상태 확인; 램프라인 초기상태 확인; 샤시라인 1초기상태 확인; 샤시라인 2초기상태 확인; 시트라인 초기상태 확인; 리턴라인 초기상태 확인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

7

Ladder | 10/2/2026

# Data Name : 1__MAIN

8

Ladder | 10/2/2026

# Data Name : 1__MAIN

9

Ladder | 10/2/2026

# Data Name : 1__MAIN

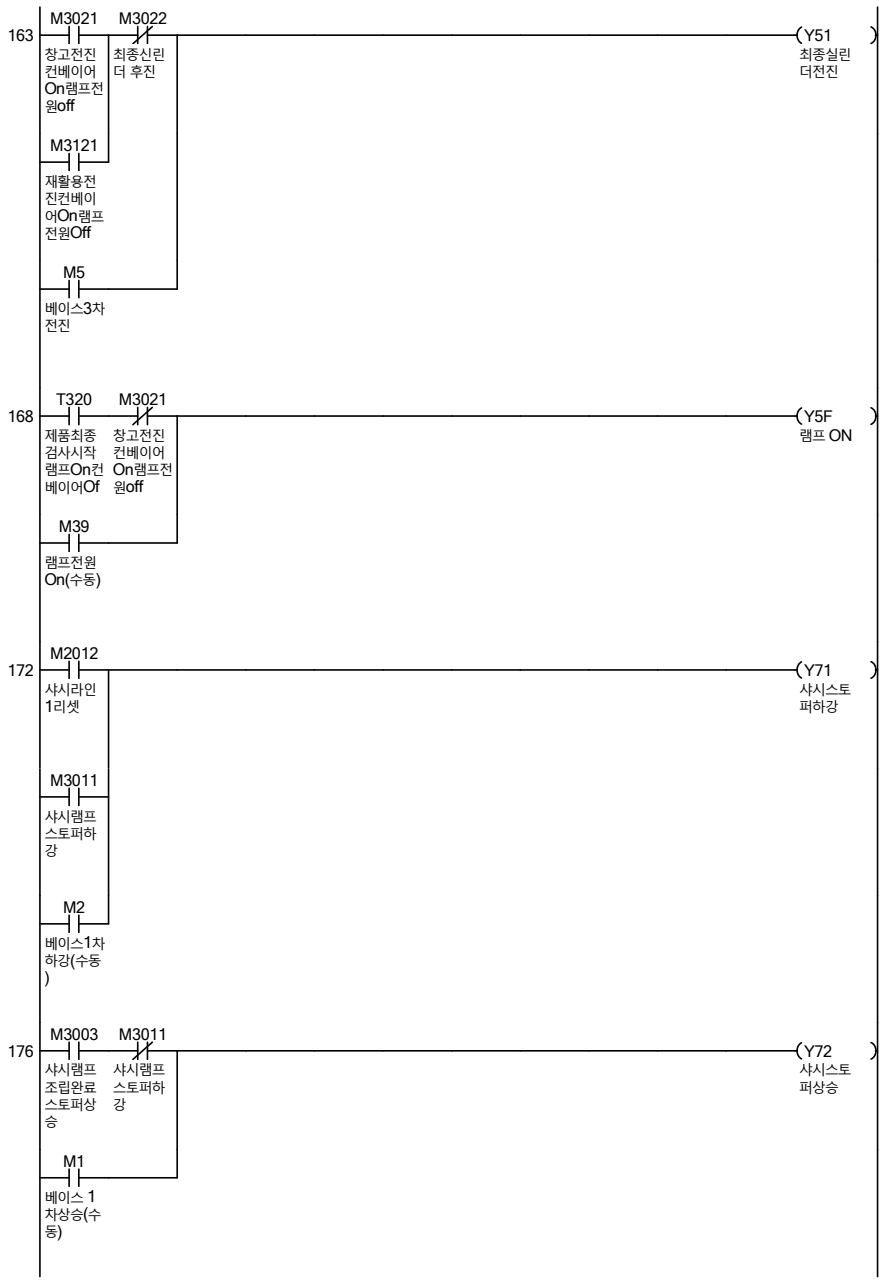
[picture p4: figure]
창고전진 컨베이어 On램프전 원off; 최종신린 더 후진; Y51 최종실린 더전진; 재활용전 진컨베이 어 램프 On 전원Off; 베이스 차3 전진; 제품최종 검사시작 램프 컨 On 베이어Of; 램프전원; 샤시라인 1리셋; Y71 샤시스토 퍼하강; 샤시램프 스토퍼하 강; 베이스 차1 하강 수동 ( ); 샤시램프 조립완료 스토퍼상 승; Y72 샤시스토 퍼상승; 베이스 1 차상승 수( 동)

10

Ladder | 10/2/2026

# Data Name : 1__MAIN

11

Ladder | 10/2/2026

# Data Name : 1__MAIN

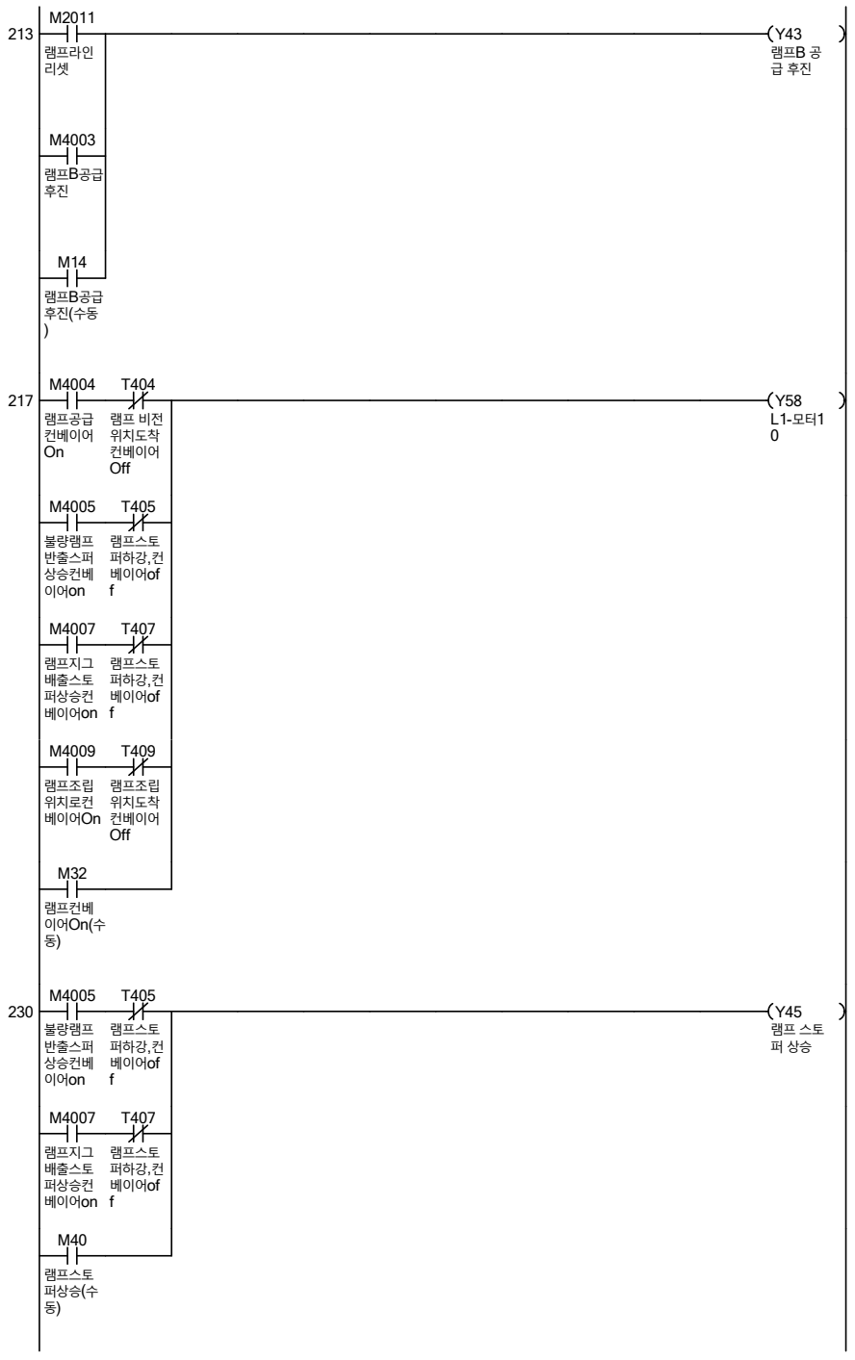
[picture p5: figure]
램프라인 리셋; 램프공급 컨베이어 On; 램프 비전 위치도착 컨베이어 Off; 불량램프 반출스퍼 상승컨베 이어on; 램프스토 퍼하강 컨, 베이어of f; 램프지그 배출스토 퍼상승컨 베이어on; 램프조립 위치로컨 베이어On; 램프조립 위치도착 컨베이어 Off; 램프컨베; 램프스토 퍼상승 수( 동)

12

Ladder | 10/2/2026

# Data Name : 1__MAIN

13

Ladder | 10/2/2026

# Data Name : 1__MAIN

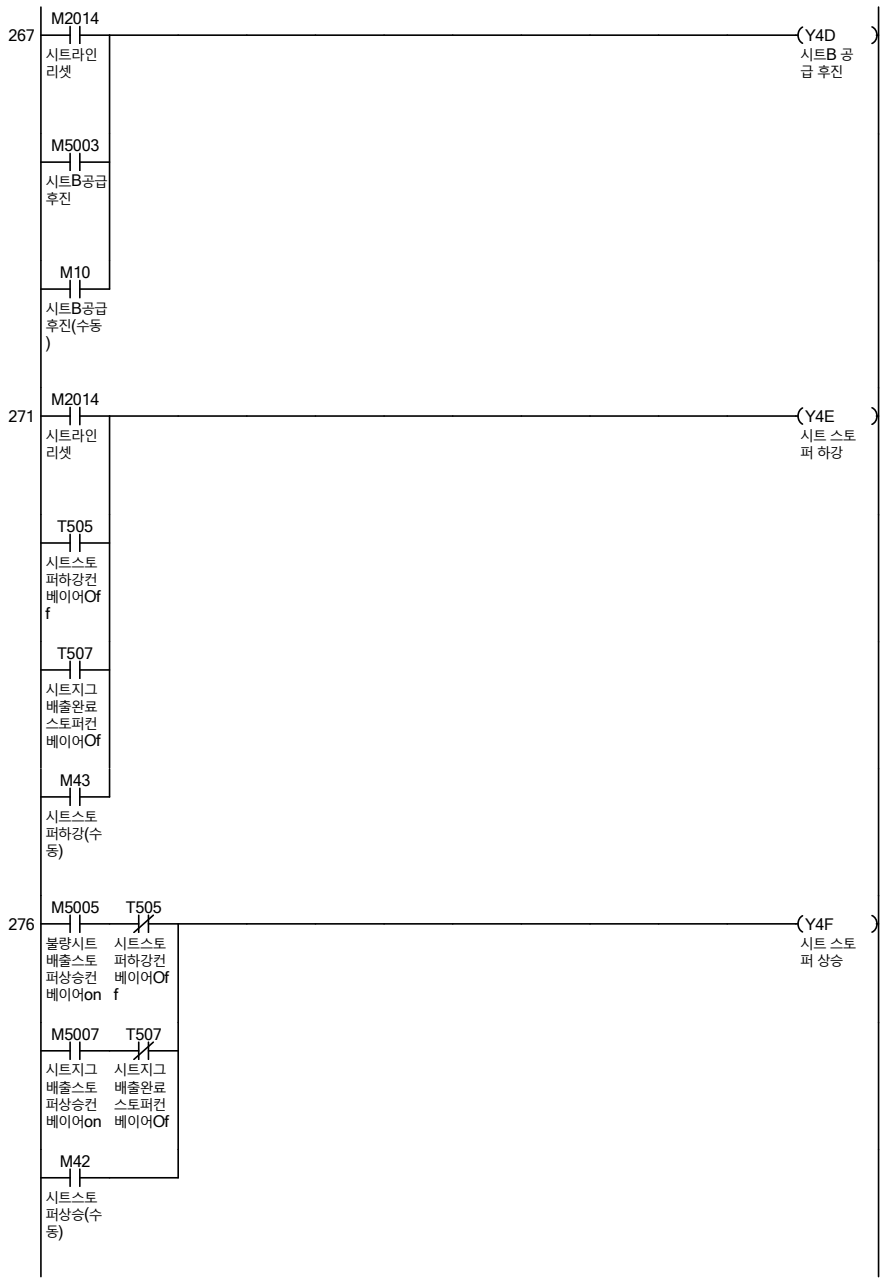
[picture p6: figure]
시트라인 리셋; 시트스토 퍼하강컨 베이어Of f; 시트지그 배출완료 스토퍼컨 베이어Of; 시트스토 퍼하강 수( 동); 불량시트 배출스토 퍼상승컨 베이어on; 시트지그 배출스토 퍼상승컨 베이어on; 시트스토 퍼상승 수( 동)

14

Ladder | 10/2/2026

# Data Name : 1__MAIN

15

Ladder | 10/2/2026

# Data Name : 1__MAIN

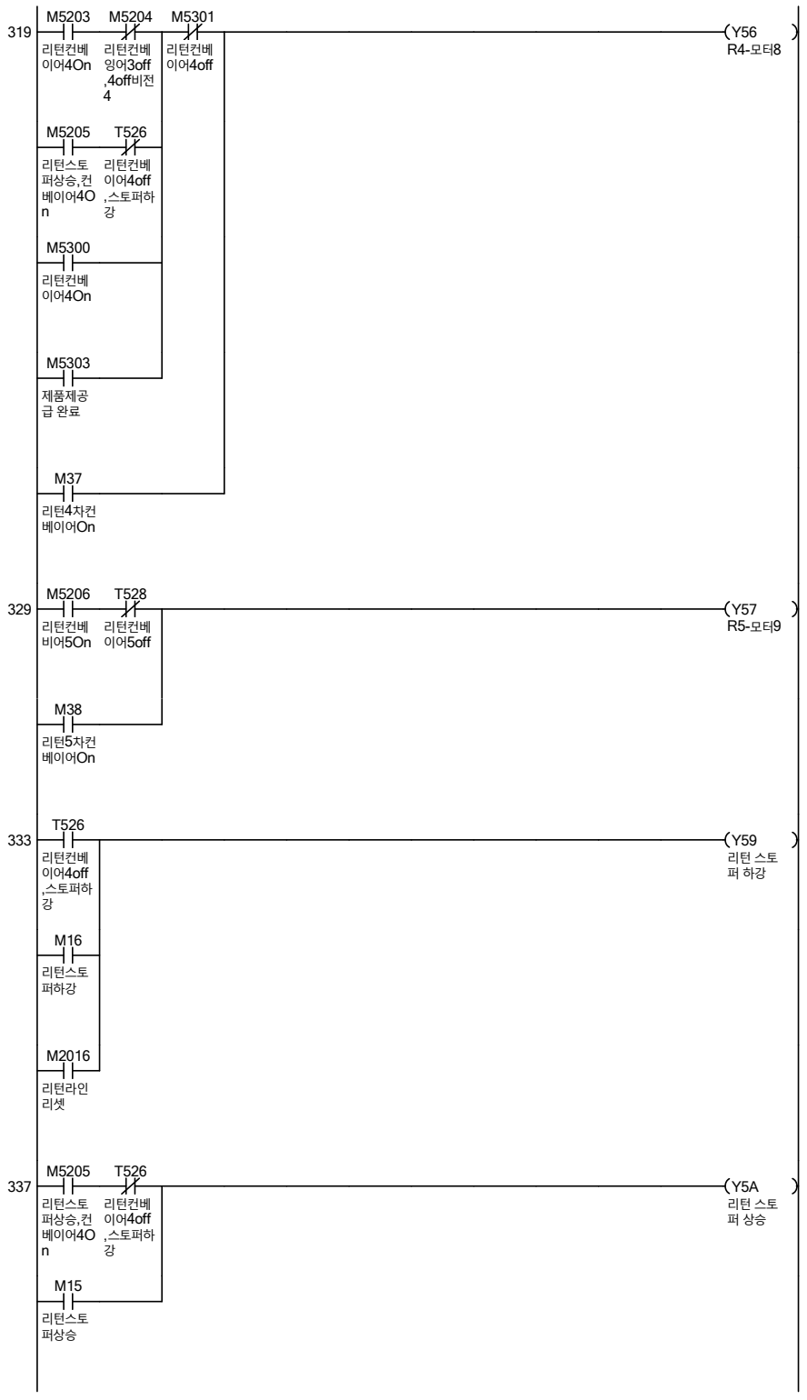
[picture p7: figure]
리턴컨베 이어4On; 리턴컨베 잉어3off ,4off비전 4; 리턴컨베 이어4off; 리턴스토 퍼상승 컨, 베이어4O n; 리턴컨베 이어4off ,스토퍼하 강; 제품제공 급 완료; 리턴 차컨 4 베이어On; 리턴컨베 비어5On; 리턴컨베 이어5off; 리턴 차컨 5 베이어On; 리턴스토 퍼하강; 리턴라인 리셋; 리턴스토 퍼상승

16

341 END

Ladder | 10/2/2026

# Data Name : 1__MAIN

17

Ladder | 10/2/2026

# Data Name : 2__BODY

18

Ladder | 10/2/2026

# Data Name : 2__BODY

19

Ladder | 10/2/2026

# Data Name : 2__BODY

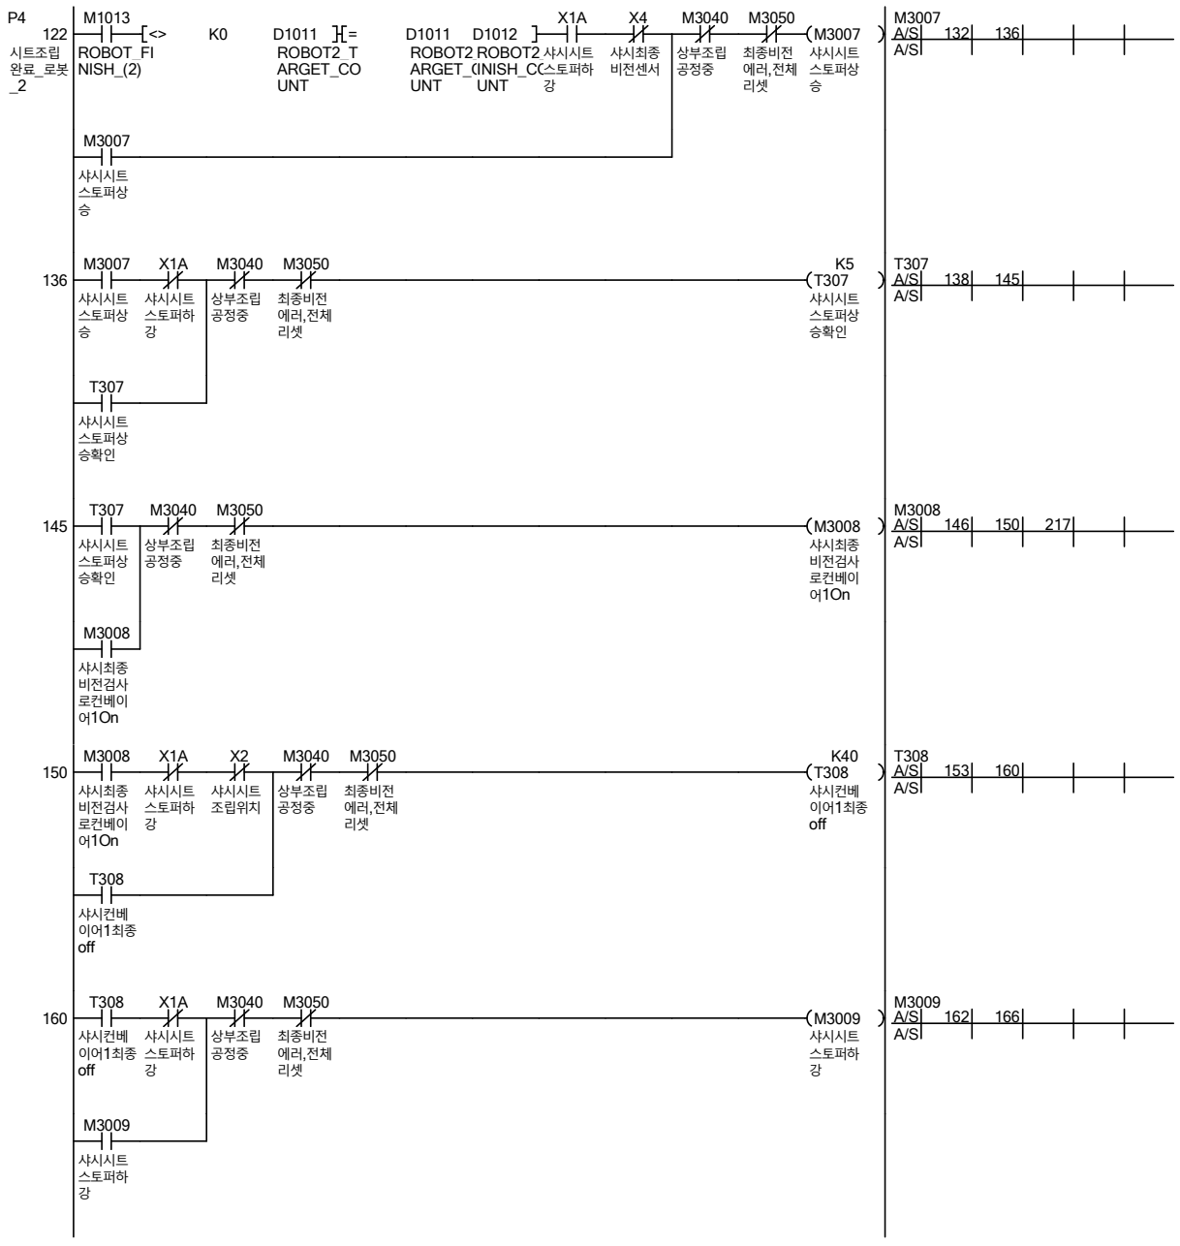
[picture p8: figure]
시트조립 완료 로봇 _ _2; ROBOT_FI NISH_(2); ROBOT2_T ARGET_CO UNT; D1012 ROBOT2_F INISH_CO UNT; 샤시시트 스토퍼하 강; 샤시최종 비전센서; 상부조립 공정중; 최종비전 에러 전체 , 리셋; M3007 샤시시트 스토퍼상 승; 샤시시트 스토퍼상 승; K5 T307 샤시시트 스토퍼상 승확인; 샤시시트 스토퍼상 승확인; M3008 샤시최종 비전검사 로컨베이 어1On; 샤시최종 비전검사 로컨베이 어1On; 샤시시트 조립위치; K40 T308 샤시컨베 이어 최종 1 off; 샤시컨베 이어 최종 1 off; M3009 샤시시트 스토퍼하 강

20

Ladder | 10/2/2026

# Data Name : 2__BODY

21

Ladder | 10/2/2026

# Data Name : 2__BODY

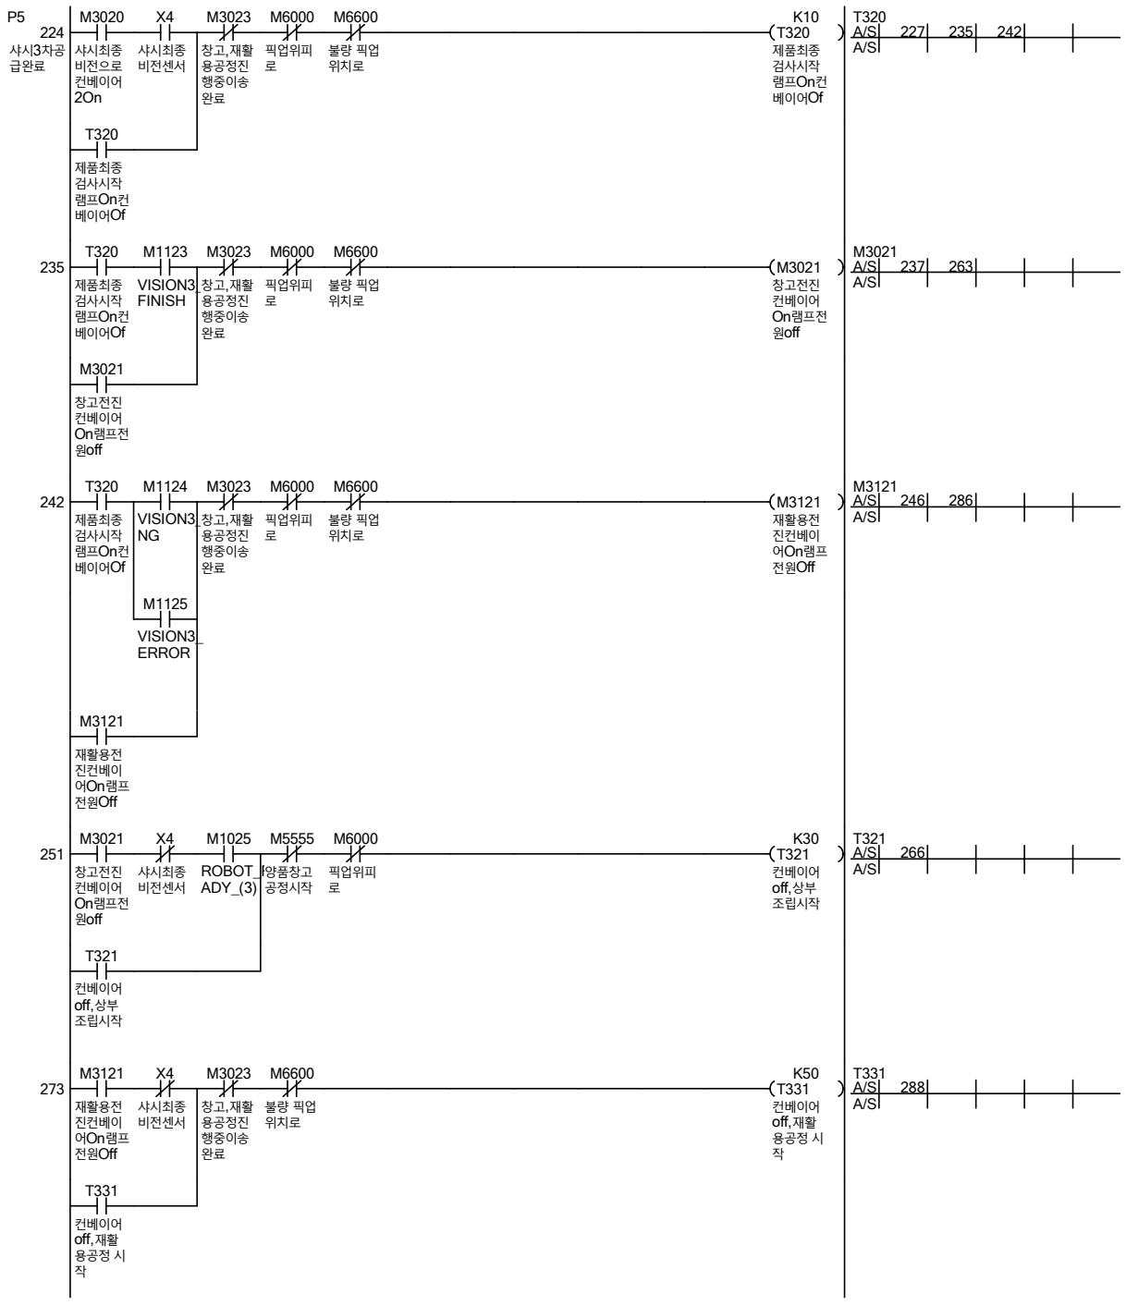
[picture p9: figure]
샤시 차공 3 급완료; 샤시최종 비전으로 컨베이어 2On; 샤시최종 비전센서; 창고 재활 , 용공정진 행중이송 완료; 픽업위피 로; 불량 픽업 위치로; K10 T320 제품최종 검사시작 램프 컨 On 베이어Of; 제품최종 검사시작 램프 컨 On 베이어Of; VISION3_ FINISH; M3021 창고전진 컨베이어 On램프전 원off; 창고전진 컨베이어 On램프전 원off; VISION3_ NG; M3121 재활용전 진컨베이 어 램프 On 전원Off; VISION3_ ERROR; 재활용전 진컨베이 어 램프 On 전원Off; ROBOT_RE ADY_(3); 양품창고 공정시작; K30 T321 컨베이어 off,상부 조립시작; 컨베이어 off,상부 조립시작; K50 T331 컨베이어 off,재활 용공정 시 작; 컨베이어 off,재활 용공정 시 작

22

Ladder | 10/2/2026

# Data Name : 2__BODY

23

Ladder | 10/2/2026

# Data Name : 3__LAMP

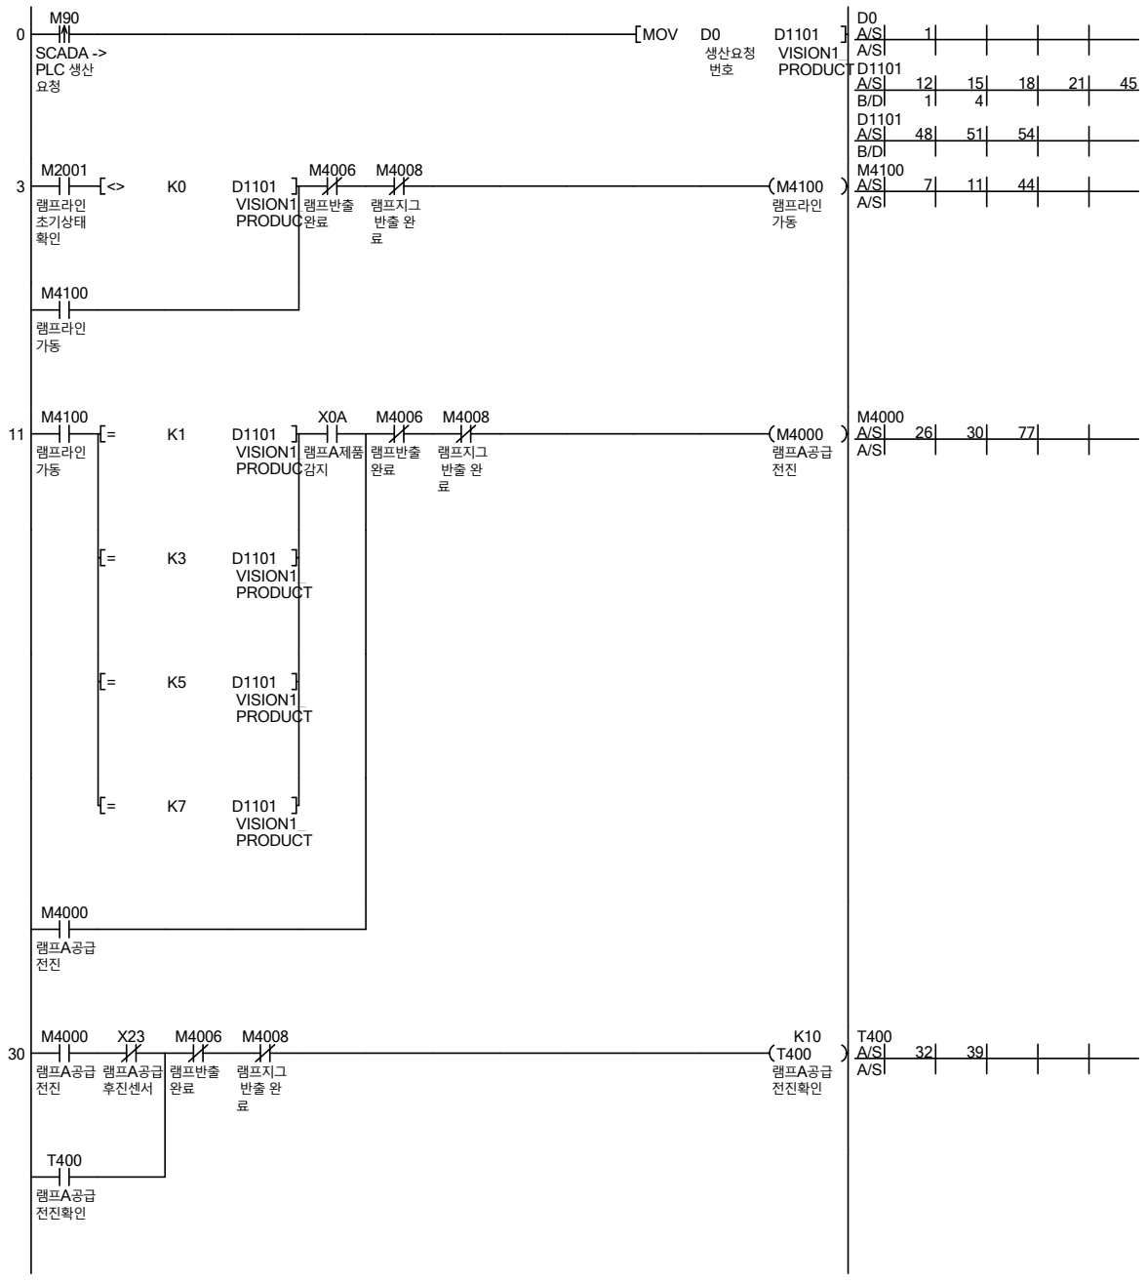
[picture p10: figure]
SCADA -> PLC 생산 요청; MOV; 생산요청 번호; D1101 VISION1_ PRODUCT; 램프라인 초기상태 확인; VISION1_ PRODUCT; 램프반출 완료; 램프지그 반출 완 료; M4100 램프라인 가동; 램프라인 가동; 램프 공급 A 후진센서; K10 T400 램프 공급 A 전진확인; 램프 공급 A 전진확인

24

Ladder | 10/2/2026

# Data Name : 3__LAMP

25

Ladder | 10/2/2026

# Data Name : 3__LAMP

26

Ladder | 10/2/2026

# Data Name : 3__LAMP

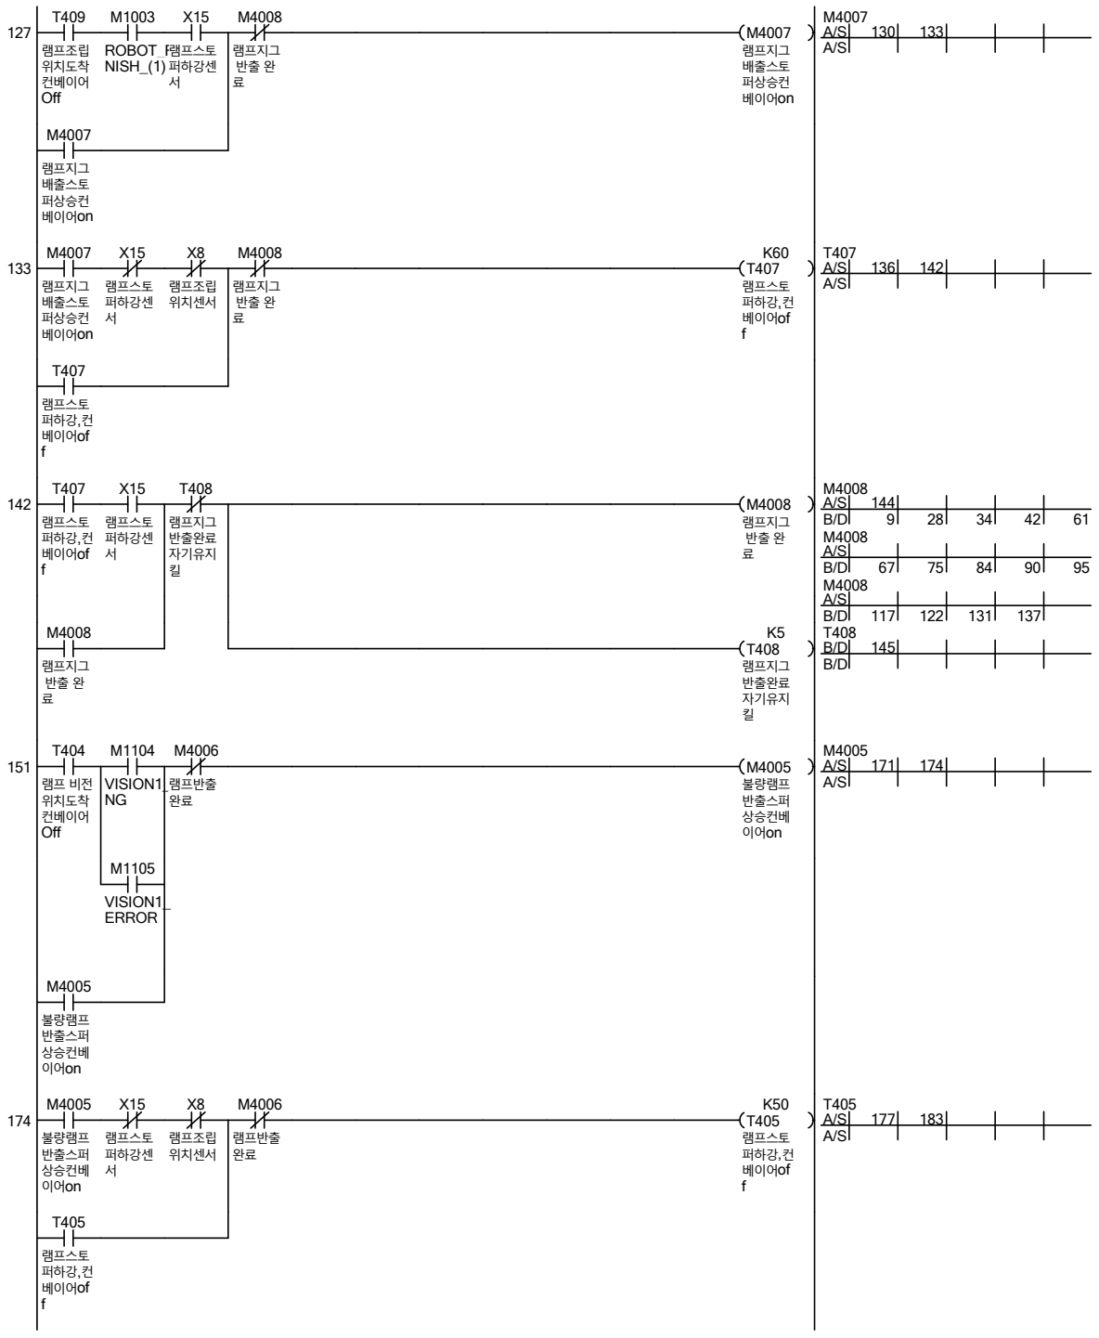
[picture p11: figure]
램프조립 위치도착 컨베이어 Off; ROBOT_FI NISH_(1); 램프스토 퍼하강센 서; 램프지그 반출 완 료; M4007 램프지그 배출스토 퍼상승컨 베이어on; 램프지그 배출스토 퍼상승컨 베이어on; 램프조립 위치센서; K60 T407 램프스토 퍼하강 컨, 베이어of f; 램프스토 퍼하강 컨, 베이어of f; 램프지그 반출완료 자기유지 킬; M4008 램프지그 반출 완 료; K5 T408 램프지그 반출완료 자기유지 킬; 램프 비전 위치도착 컨베이어 Off; VISION1_ NG; 램프반출 완료; M4005 불량램프 반출스퍼 상승컨베 이어on; VISION1_ ERROR; 불량램프 반출스퍼 상승컨베 이어on; K50 T405 램프스토 퍼하강 컨, 베이어of f

27

Ladder | 10/2/2026

# Data Name : 3__LAMP

램프스토 퍼하강 컨, 베이어of f; 램프스토 퍼하강센 서; 램프반출 완료자기 유지킬; M4006 램프반출 완료; 램프반출 완료; K5 T406 램프반출 완료자기 유지킬; 192 END

28

Ladder | 10/2/2026

# Data Name : 4__SEAT

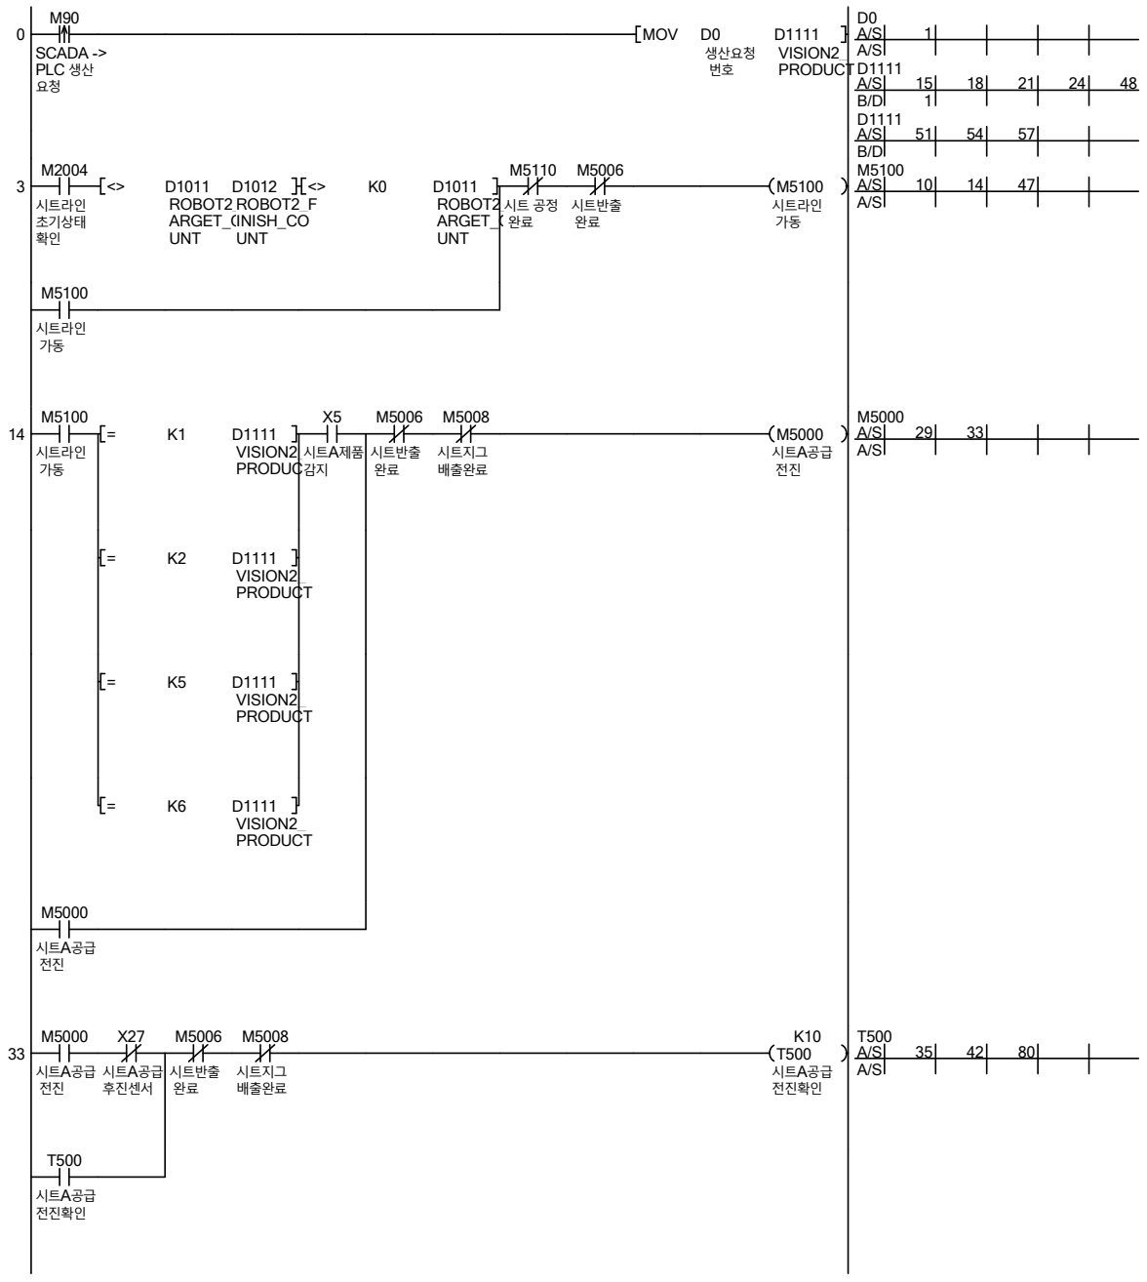
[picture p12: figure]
SCADA -> PLC 생산 요청; MOV; 생산요청 번호; D1111 VISION2_ PRODUCT; 시트라인 초기상태 확인; ROBOT2_T ARGET_CO UNT; D1012 ROBOT2_F INISH_CO UNT; 시트반출 완료; M5100 시트라인 가동; 시트라인 가동; VISION2_ PRODUCT; 시트지그 배출완료; 시트 공급 A 후진센서; K10 T500 시트 공급 A 전진확인; 시트 공급 A 전진확인

29

Ladder | 10/2/2026

# Data Name : 4__SEAT

30

Ladder | 10/2/2026

# Data Name : 4__SEAT

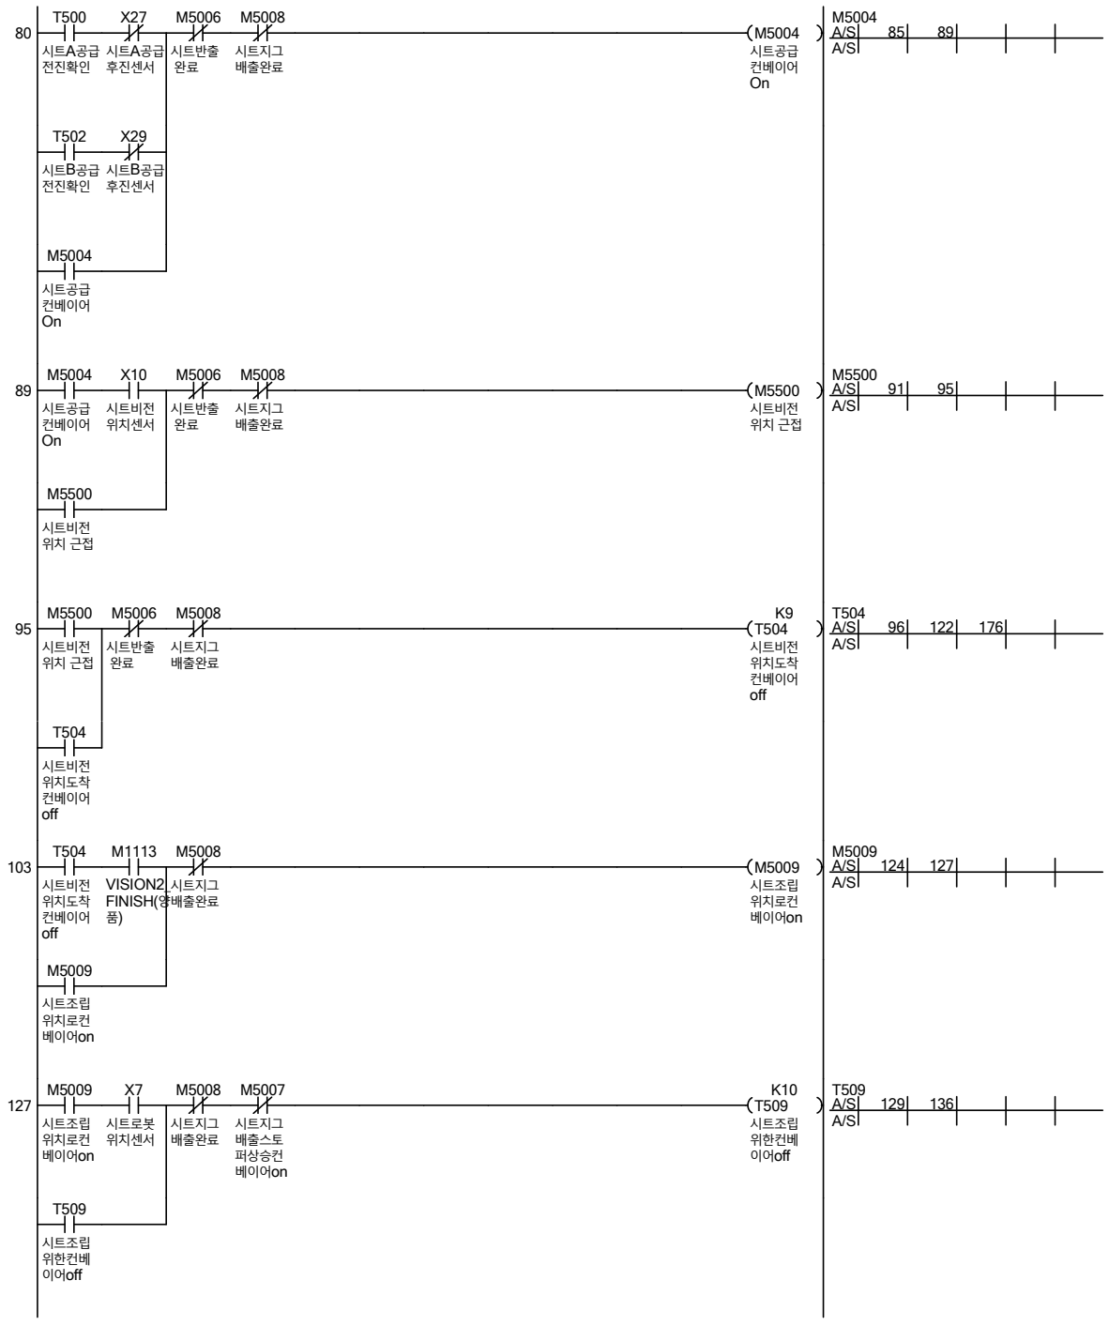
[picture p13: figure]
시트 공급 A 전진확인; 시트 공급 A 후진센서; 시트반출 완료; 시트지그 배출완료; M5004 시트공급 컨베이어 On; 시트 공급 B 전진확인; 시트 공급 B 후진센서; 시트공급 컨베이어 On; 시트비전 위치센서; M5500 시트비전 위치 근접; 시트비전 위치 근접; K9 T504 시트비전 위치도착 컨베이어 off; 시트비전 위치도착 컨베이어 off; VISION2_ FINISH(양 품); M5009 시트조립 위치로컨 베이어on; 시트조립 위치로컨 베이어on; 시트로봇 위치센서; 시트지그 배출스토 퍼상승컨 베이어on; K10 T509 시트조립 위한컨베 이어off; 시트조립 위한컨베 이어off

31

Ladder | 10/2/2026

# Data Name : 4__SEAT

32

Ladder | 10/2/2026

# Data Name : 4__SEAT

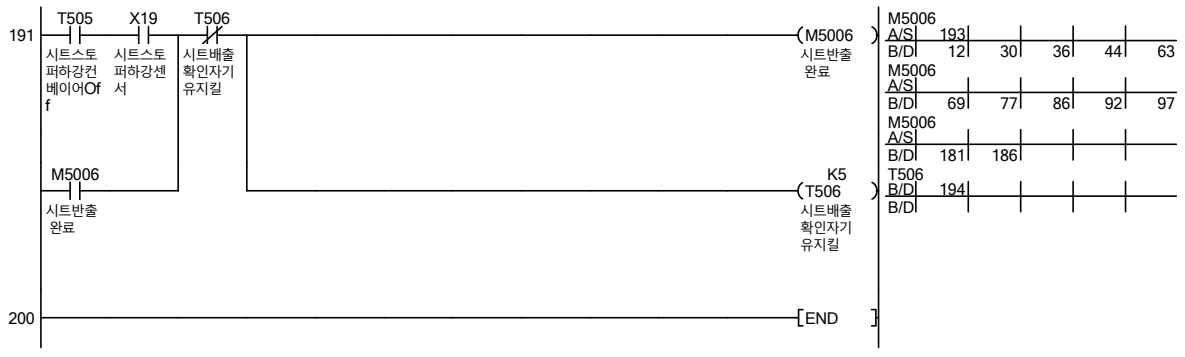
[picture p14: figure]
시트스토 퍼하강컨 베이어Of f; 시트스토 퍼하강센 서; 시트배출 확인자기 유지킬; M5006 시트반출 완료; 시트반출 완료; K5 T506 시트배출 확인자기 유지킬; 200 END

33

Ladder | 10/2/2026

# Data Name : 5__ROBOT

34

Ladder | 10/2/2026

# Data Name : 5__ROBOT

ROBOT_FI NISH_(2); INCP; ROBOT2_F INISH_CO UNT; 샤시시트 스토퍼상 승; MOV; ROBOT2_T ARGET_CO UNT; 컨베이어 off,상부 조립시작; ROBOT_RU NNING_(3 ); M1021 ROBOT_ST ART_(3); 리턴제품 재공급로 봇 시작 4; ROBOT_RU NNING_(4 ); M1031 ROBOT_ST ART_(4); 60 END

35

Ladder | 10/2/2026

# Data Name : 6__VI

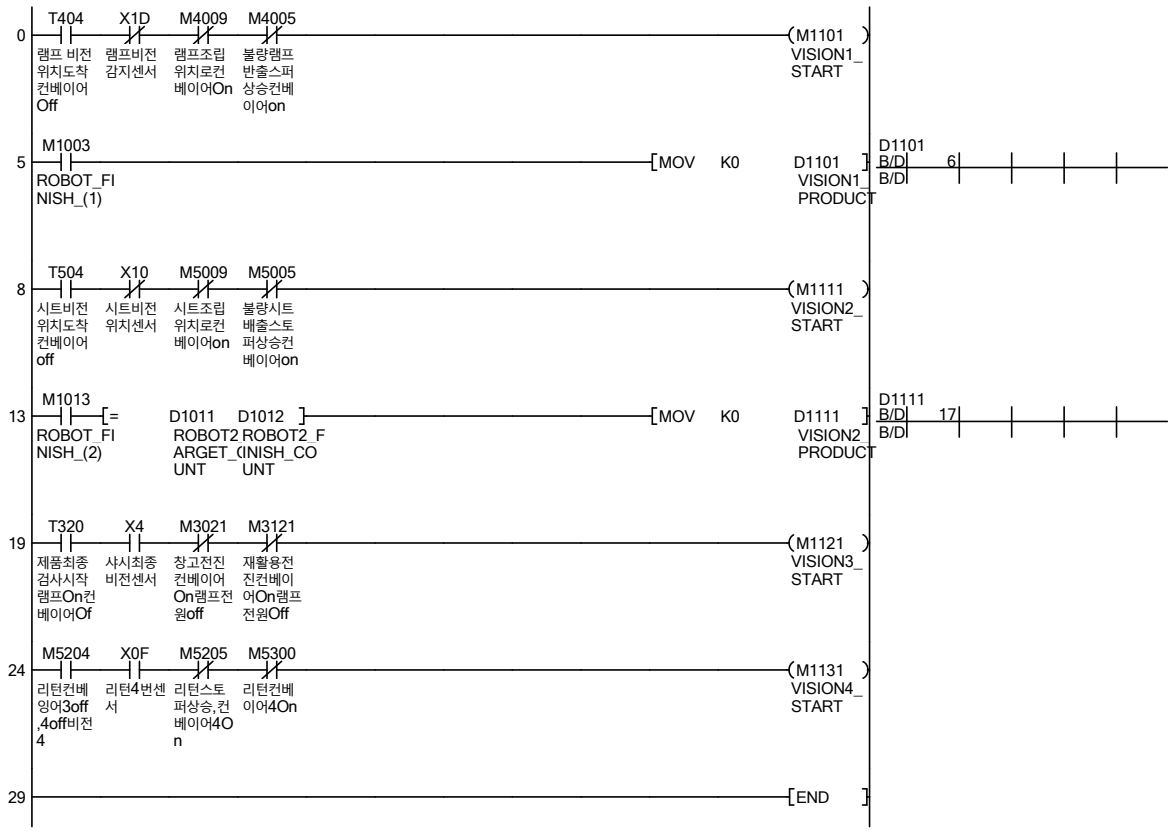
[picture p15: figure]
램프 비전 위치도착 컨베이어 Off; 램프비전 감지센서; 램프조립 위치로컨 베이어On; 불량램프 반출스퍼 상승컨베 이어on; M1101 VISION1_ START; ROBOT_FI NISH_(1); MOV; VISION1_ PRODUCT; 시트비전 위치도착 컨베이어 off; 시트비전 위치센서; 시트조립 위치로컨 베이어on; 불량시트 배출스토 퍼상승컨 베이어on; M1111 VISION2_ START; ROBOT_FI NISH_(2); ROBOT2_T ARGET_CO UNT; D1012 ROBOT2_F INISH_CO UNT; VISION2_ PRODUCT; 제품최종 검사시작 램프 컨 On 베이어Of; 샤시최종 비전센서; 창고전진 컨베이어 On램프전 원off; 재활용전 진컨베이 어 램프 On 전원Off; M1121 VISION3_ START; 리턴컨베 잉어3off ,4off비전 4; 리턴스토 퍼상승 컨, 베이어4O n; 리턴컨베 이어4On; M1131 VISION4_ START; 29 END

36

Ladder | 10/2/2026

# Data Name : 7__RE

37

Ladder | 10/2/2026

# Data Name : 7__RE

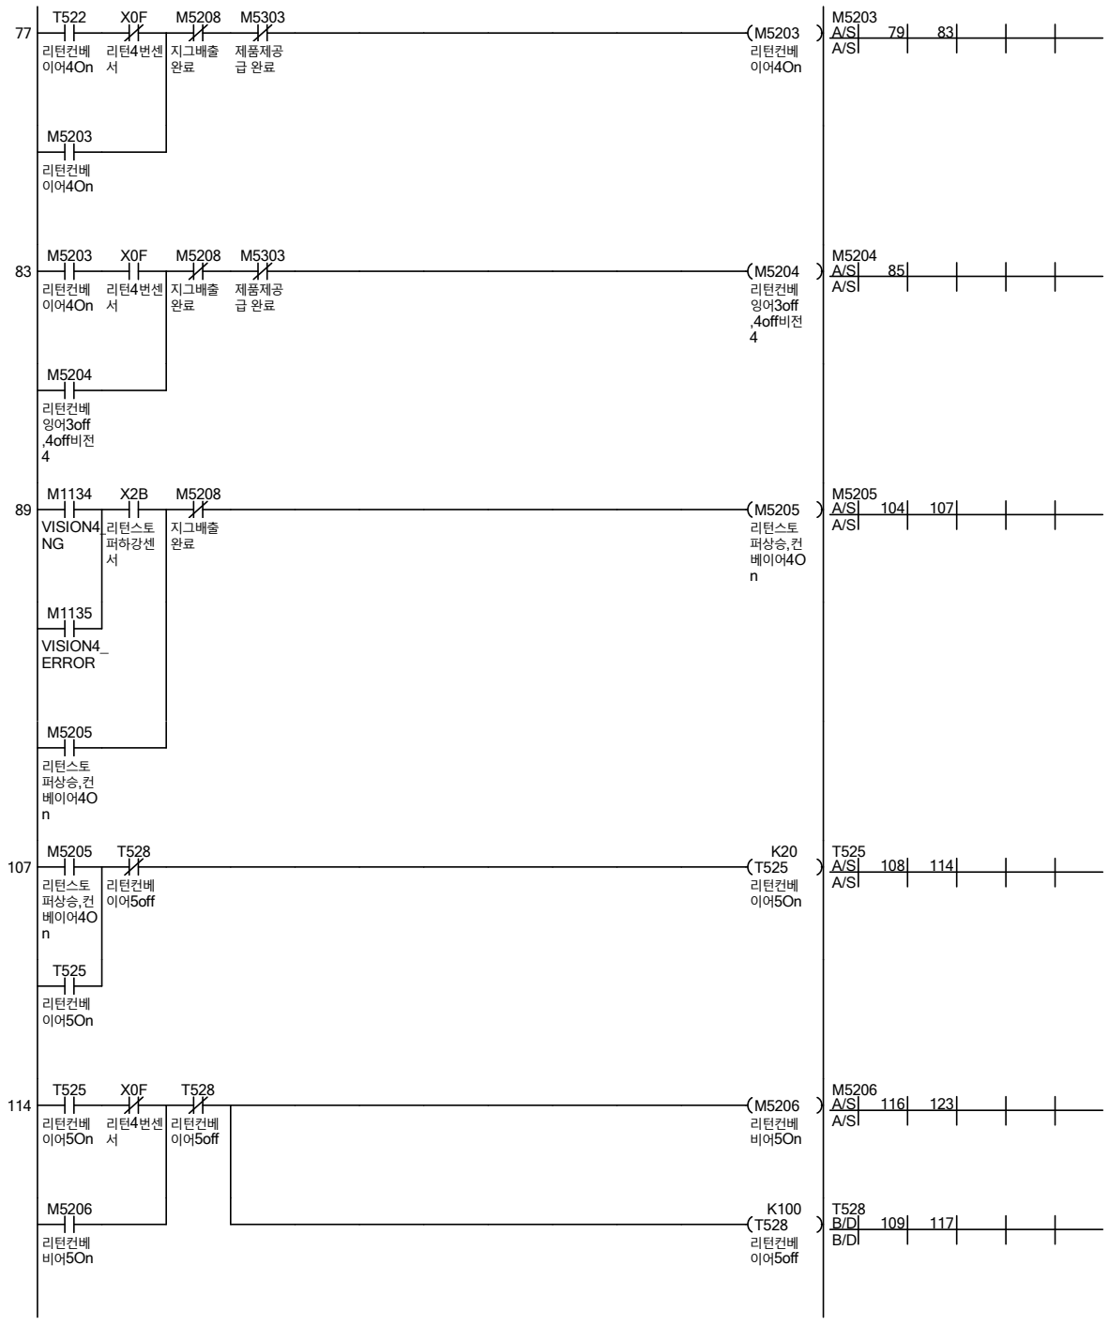
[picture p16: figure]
리턴컨베 이어4On; 지그배출 완료; 제품제공 급 완료; M5203 리턴컨베 이어4On; M5204 리턴컨베 잉어3off ,4off비전 4; 리턴컨베 잉어3off ,4off비전 4; VISION4_ NG; 리턴스토 퍼하강센 서; M5205 리턴스토 퍼상승 컨, 베이어4O n; VISION4_ ERROR; 리턴스토 퍼상승 컨, 베이어4O n; 리턴컨베 이어5off; K20 T525 리턴컨베 이어5On; 리턴컨베 이어5On; M5206 리턴컨베 비어5On; 리턴컨베 비어5On; K100 T528 리턴컨베 이어5off

38

Ladder | 10/2/2026

# Data Name : 7__RE

39

Ladder | 10/2/2026

# Data Name : 7__RE

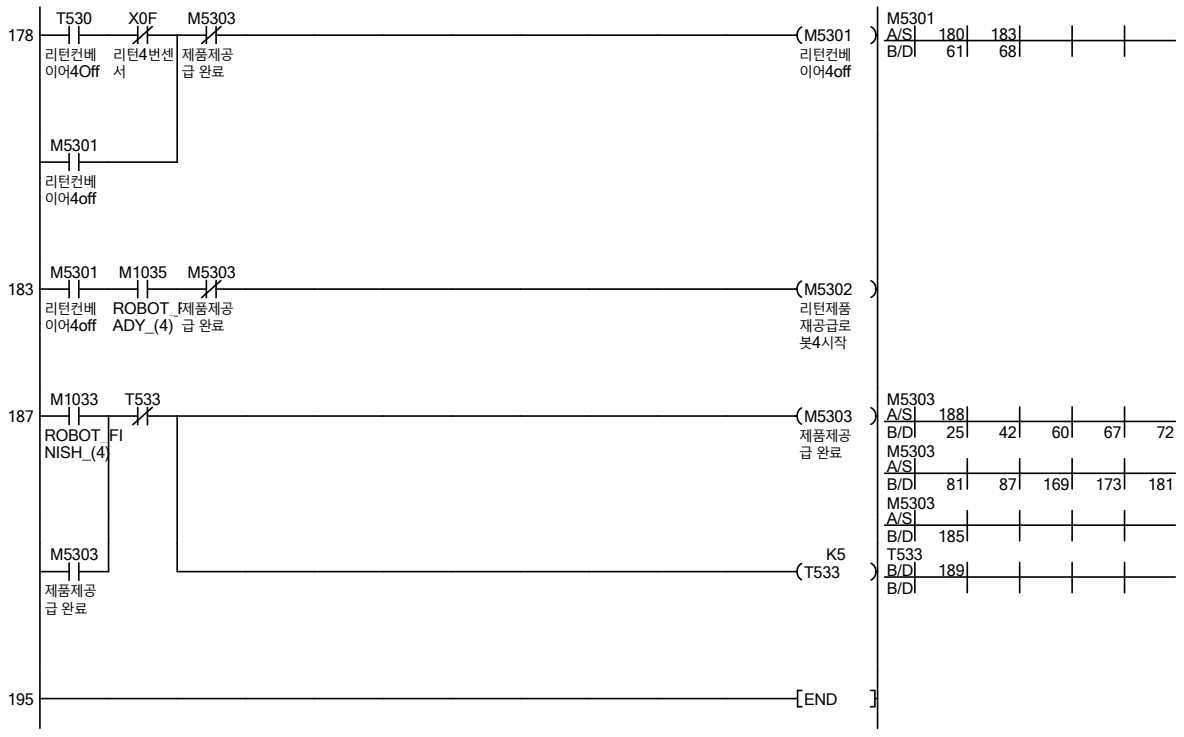
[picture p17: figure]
리턴컨베 이어4Off; 제품제공 급 완료; M5301 리턴컨베 이어4off; 리턴컨베 이어4off; ROBOT_RE ADY_(4); M5302 리턴제품 재공급로 봇 시작 4; ROBOT_FI NISH_(4); M5303 제품제공 급 완료; 195 END

40

Ladder | 10/2/2026

# Data Name : 8__V_4

VISION1_ PRODUCT; 비전 필요 4 데이터옮 겨놓기; VISION2_ PRODUCT; MOV; Vision4_ fake_Res ult_lamp; ROBOT_FI NISH_(1); VISION4_ CLASS_RE SULT

41

Ladder | 10/2/2026

# Data Name : 8__V_4

비전 필요 4 데이터옮 겨놓기; VISION2_ PRODUCT; MOV; Vision4_ fake_Res ult_seat; ROBOT_FI NISH_(2); 리턴컨베 잉어3off ,4off비전 4; K20 T900 비전 임4 의 검사시 간; 비전 임4 의 검사시 간

42

Ladder | 10/2/2026

# Data Name : 8__V_4

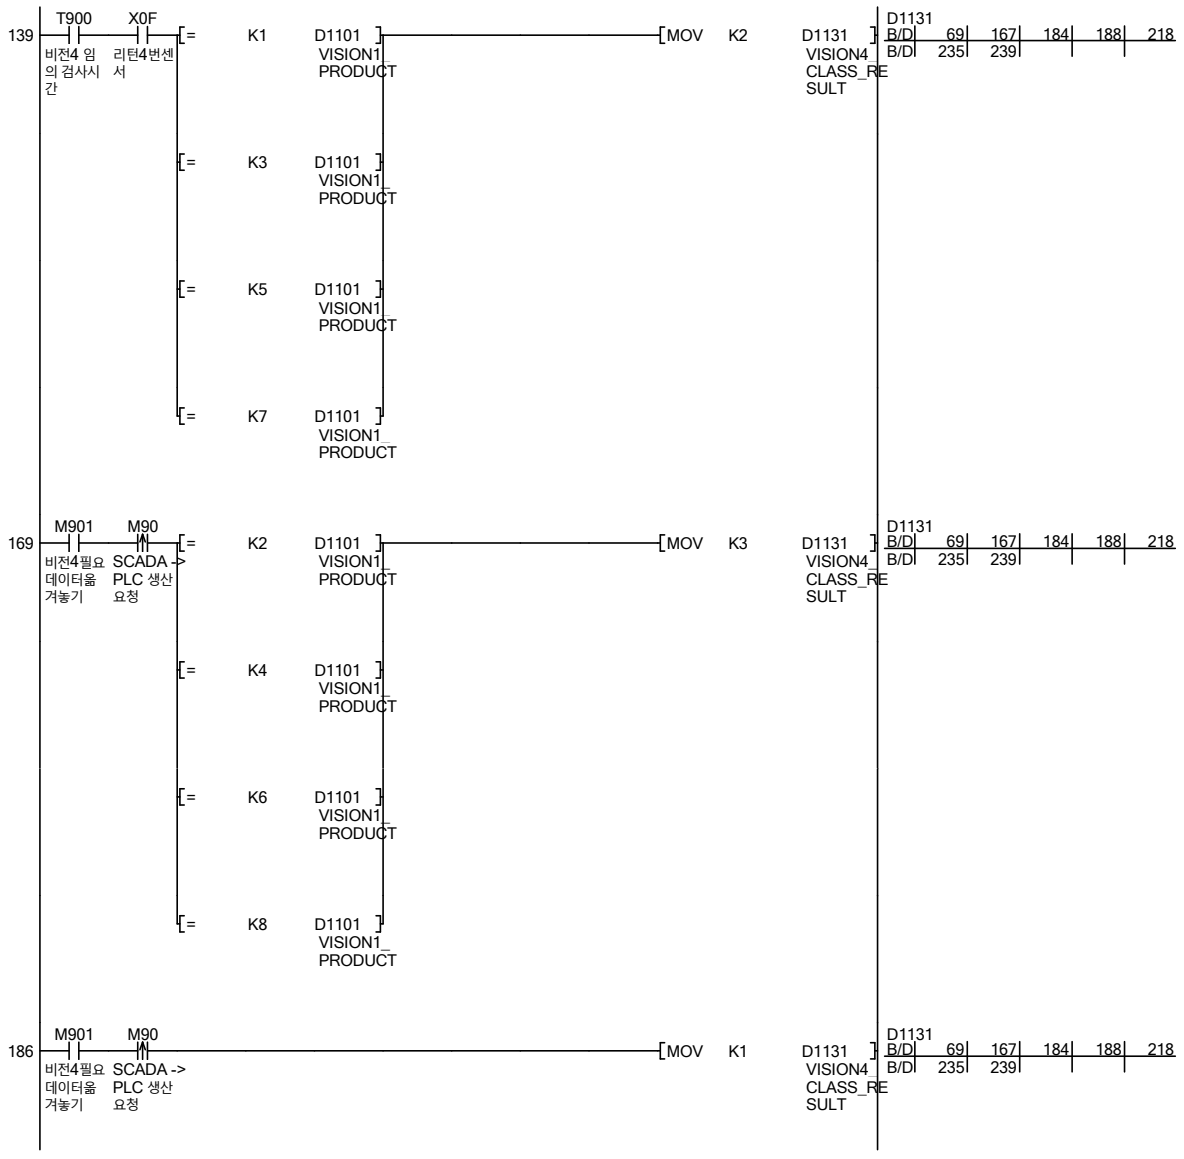
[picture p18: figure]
비전 임4 의 검사시 간; VISION1_ PRODUCT; MOV; VISION4_ CLASS_RE SULT; 비전 필요 4 데이터옮 겨놓기; SCADA -> PLC 생산 요청

43

Ladder | 10/2/2026

# Data Name : 8__V_4

비전 필요 4 데이터옮 겨놓기; SCADA -> PLC 생산 요청; VISION2_ PRODUCT; MOV; VISION4_ CLASS_RE SULT; 241 END

44

Ladder | 10/2/2026

# Data Name : 9__SERVO

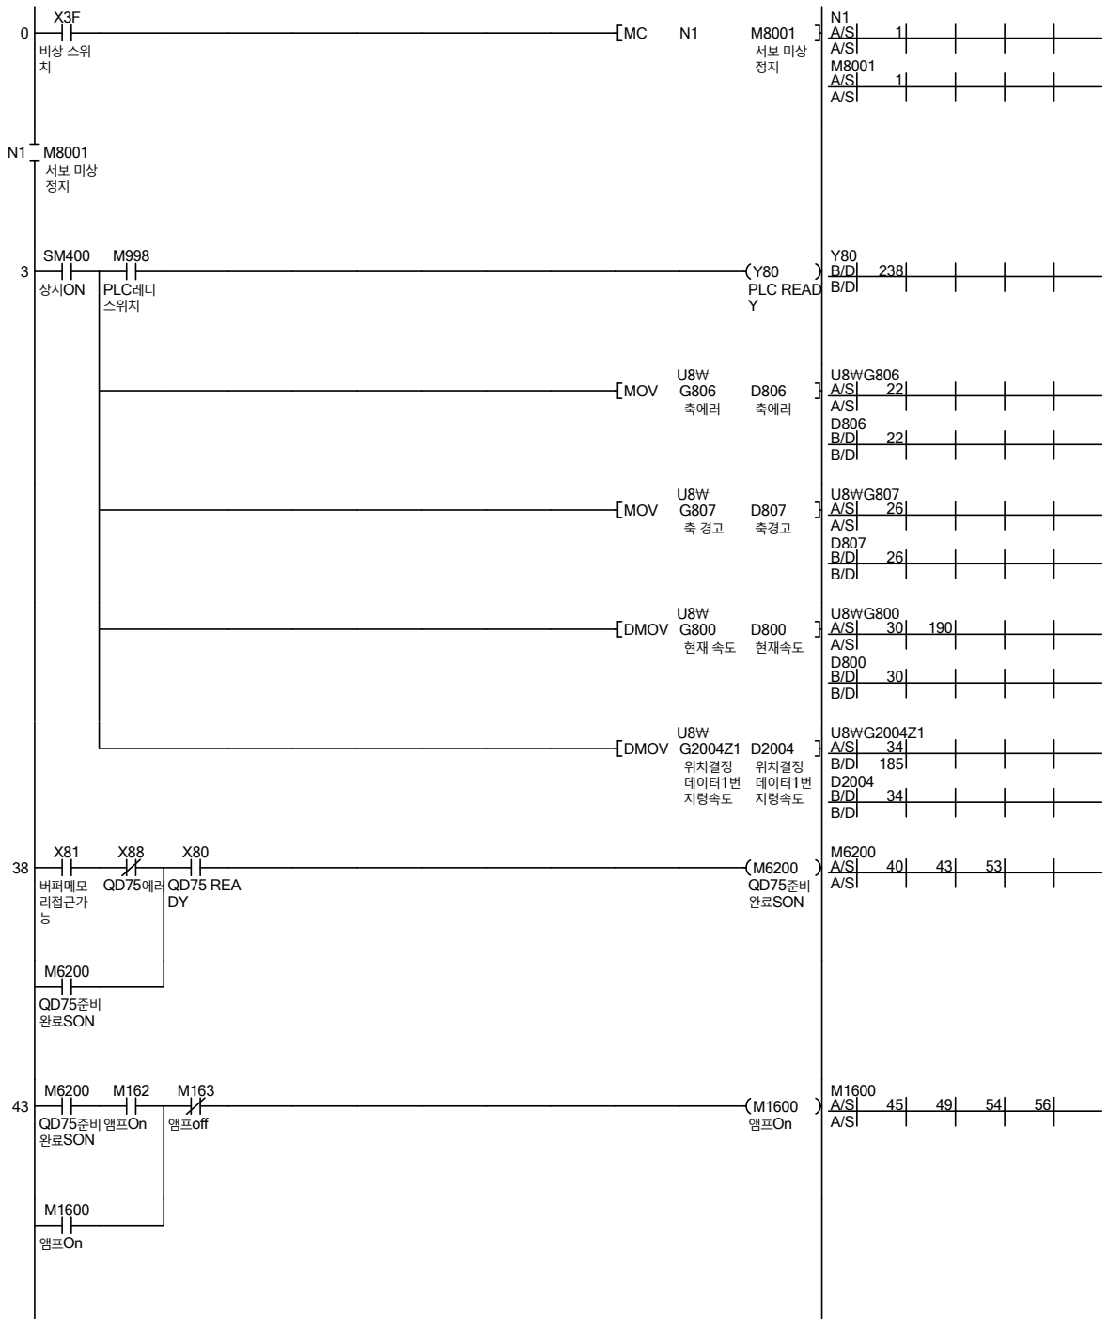
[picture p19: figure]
상시ON; PLC 레디 스위치; Y80 PLC READ Y; MOV; U8\ G806 축에러; D806 축에러; D807 축경고; DMOV; D800 현재속도; U8\ G2004Z1 위치결정 데이터 번1 지령속도; D2004 위치결정 데이터 번1 지령속도; 버퍼메모 리접근가 능; QD75 REA DY; M6200 QD75준비 완료SON; QD75준비 완료SON; 앰프On; 앰프off; M1600 앰프On

45

Ladder | 10/2/2026

# Data Name : 9__SERVO

46

Ladder | 10/2/2026

# Data Name : 9__SERVO

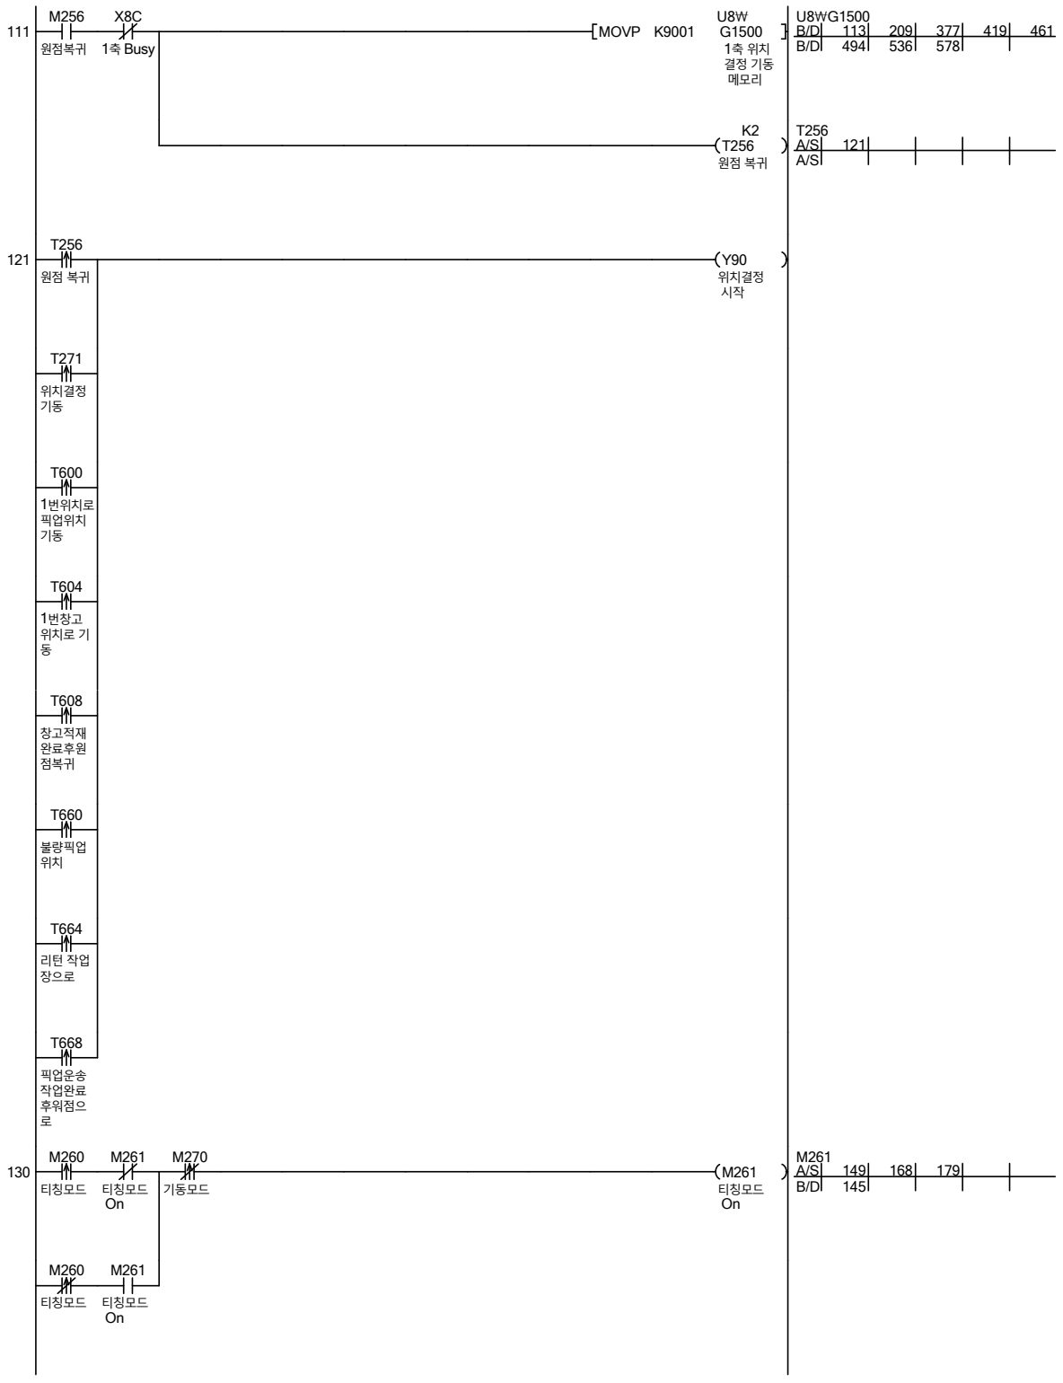
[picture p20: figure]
원점복귀; 1 Busy 축; MOVP K9001; U8\ G1500 1 축 위치 결정 기동 메모리; Y90 위치결정 시작; 위치결정 기동; 1번위치로 픽업위치 기동; 1 번창고 위치로 기 동; 창고적재 완료후원 점복귀; 불량픽업 위치; 리턴 작업 장으로; 픽업운송 작업완료 후워점으 로; 티칭모드; 티칭모드 On; 기동모드; M261 티칭모드 On

47

Ladder | 10/2/2026

# Data Name : 9__SERVO

48

Ladder | 10/2/2026

# Data Name : 9__SERVO

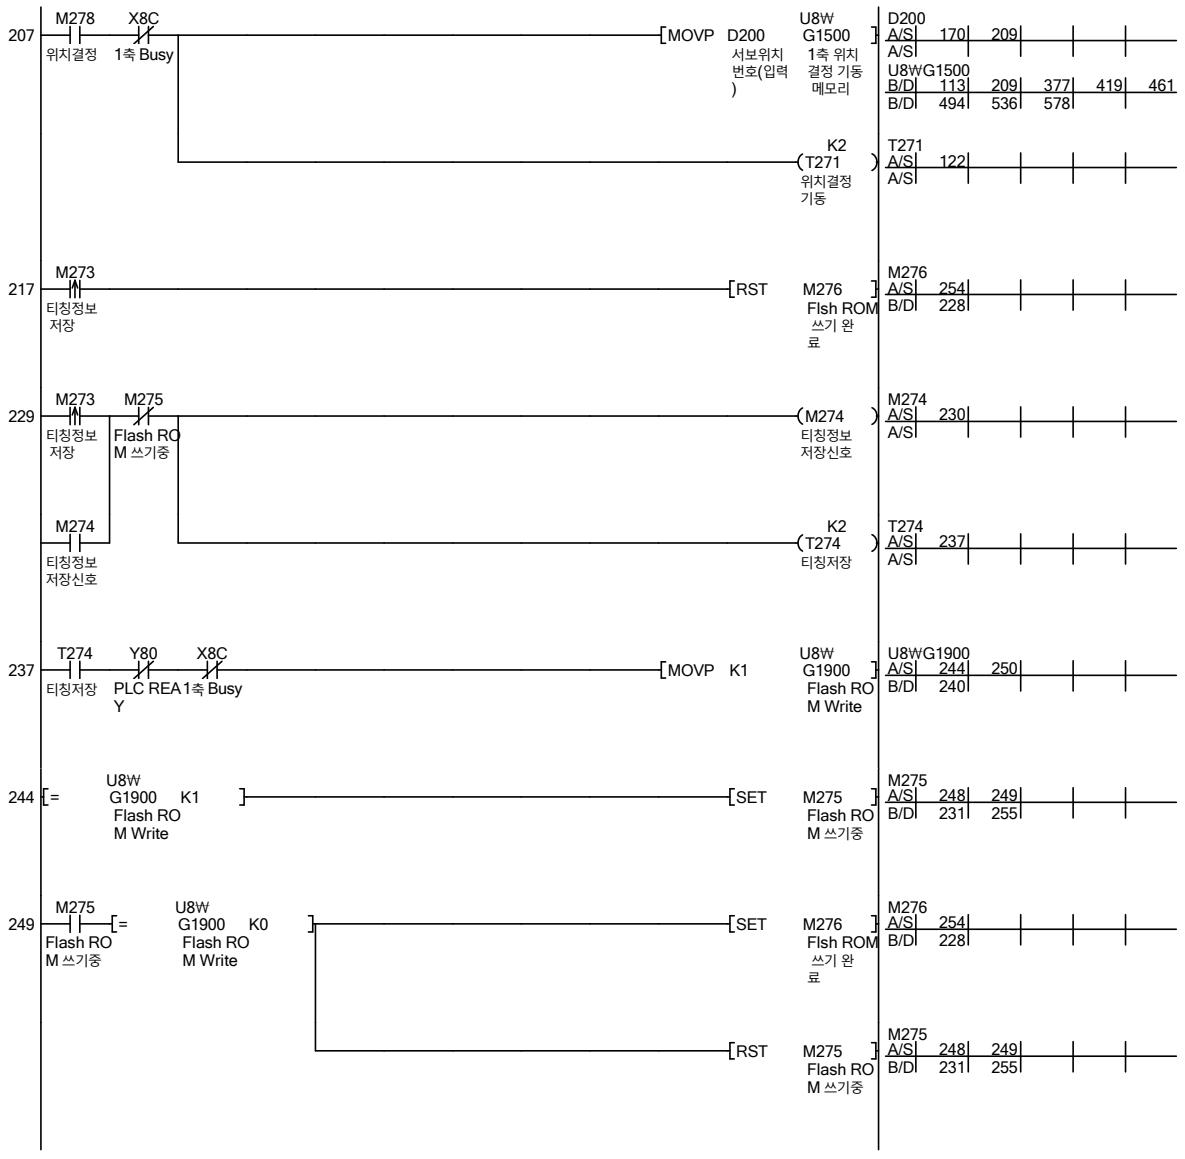
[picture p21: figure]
위치결정; 1 Busy 축; MOVP D200 서보위치 번호 입력 ( ); U8\ G1500 1 축 위치 결정 기동 메모리; K2 T271 위치결정 기동; 티칭정보 저장; RST; Flsh ROM 쓰기 완 료; Flash RO M 쓰기중; M274 티칭정보 저장신호; 티칭정보 저장신호; K2 T274 티칭저장; 티칭저장; PLC READ Y; MOVP K1; U8\ G1900 Flash RO M Write; SET

49

Ladder | 10/2/2026

# Data Name : 9__SERVO

50

Ladder | 10/2/2026

# Data Name : 9__SERVO

51

Ladder | 10/2/2026

# Data Name : 9__SERVO

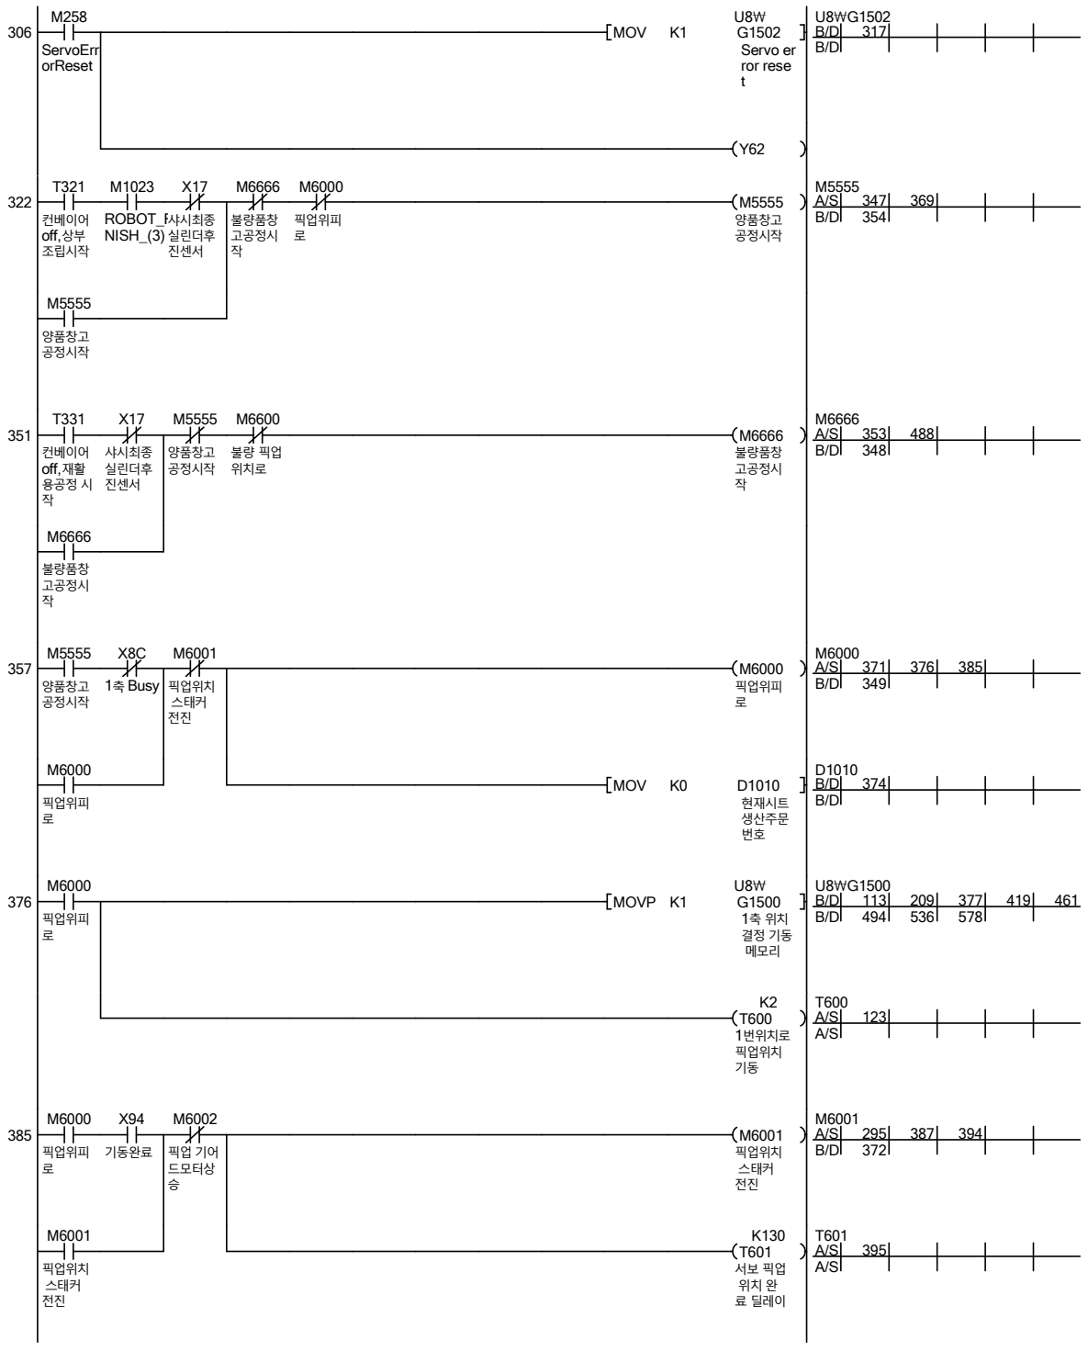
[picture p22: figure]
ServoErr orReset; MOV; U8\ G1502 Servo er ror rese t; 컨베이어 off,상부 조립시작; ROBOT_FI NISH_(3); 샤시최종 실린더후 진센서; 불량품창 고공정시 작; 픽업위피 로; M5555 양품창고 공정시작; 양품창고 공정시작; 컨베이어 off,재활 용공정 시 작; 불량 픽업 위치로; M6666 불량품창 고공정시 작; 1 Busy 축; 픽업위치 스태커 전진; M6000 픽업위피 로; 현재시트 생산주문 번호; MOVP K1; U8\ G1500 1 축 위치 결정 기동 메모리; K2 T600 1번위치로 픽업위치 기동; 기동완료; 픽업 기어 드모터상 승; M6001 픽업위치 스태커 전진; K130 T601 서보 픽업 위치 완 료 딜레이

52

Ladder | 10/2/2026

# Data Name : 9__SERVO

53

Ladder | 10/2/2026

# Data Name : 9__SERVO

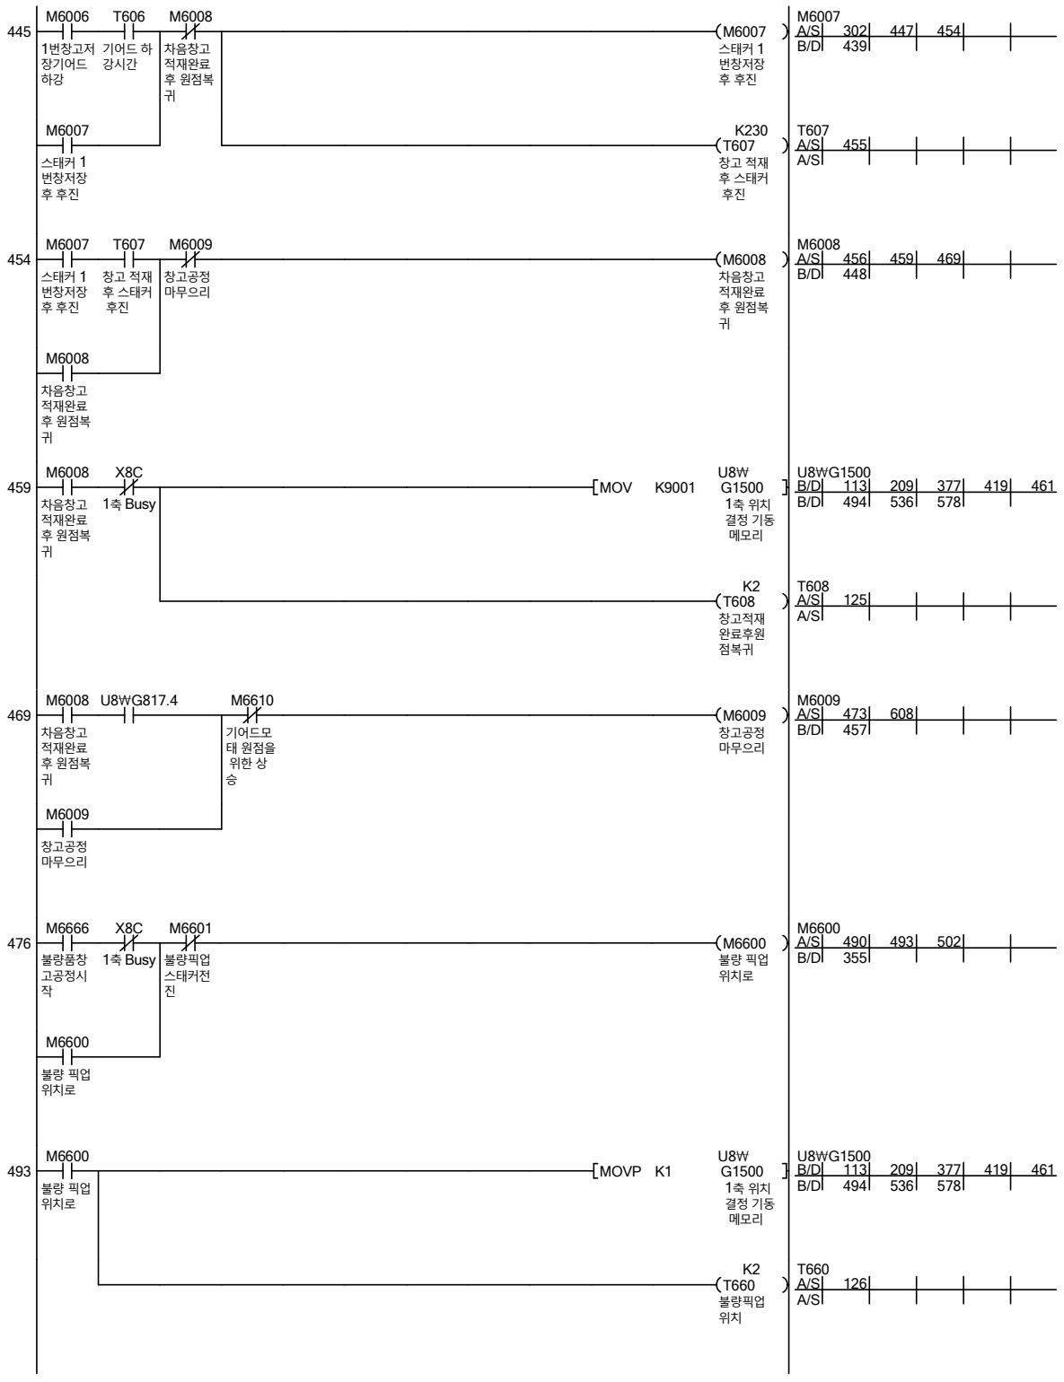
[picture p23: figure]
1번창고저 장기어드 하강; 기어드 하 강시간; 차음창고 적재완료 후 원점복 귀; M6007 스태커 1 번창저장 후 후진; 스태커 1 번창저장 후 후진; K230 T607 창고 적재 후 스태커 후진; 창고 적재 후 스태커 후진; 창고공정 마무으리; M6008 차음창고 적재완료 후 원점복 귀; 1 Busy 축; MOV; U8\ G1500 1 축 위치 결정 기동 메모리; K2 T608 창고적재 완료후원 점복귀; 기어드모 태 원점을 위한 상 승; M6009 창고공정 마무으리; 불량품창 고공정시 작; 불량픽업 스태커전 진; M6600 불량 픽업 위치로; 불량 픽업 위치로; MOVP K1; K2 T660 불량픽업 위치

54

Ladder | 10/2/2026

# Data Name : 9__SERVO

55

Ladder | 10/2/2026

# Data Name : 9__SERVO

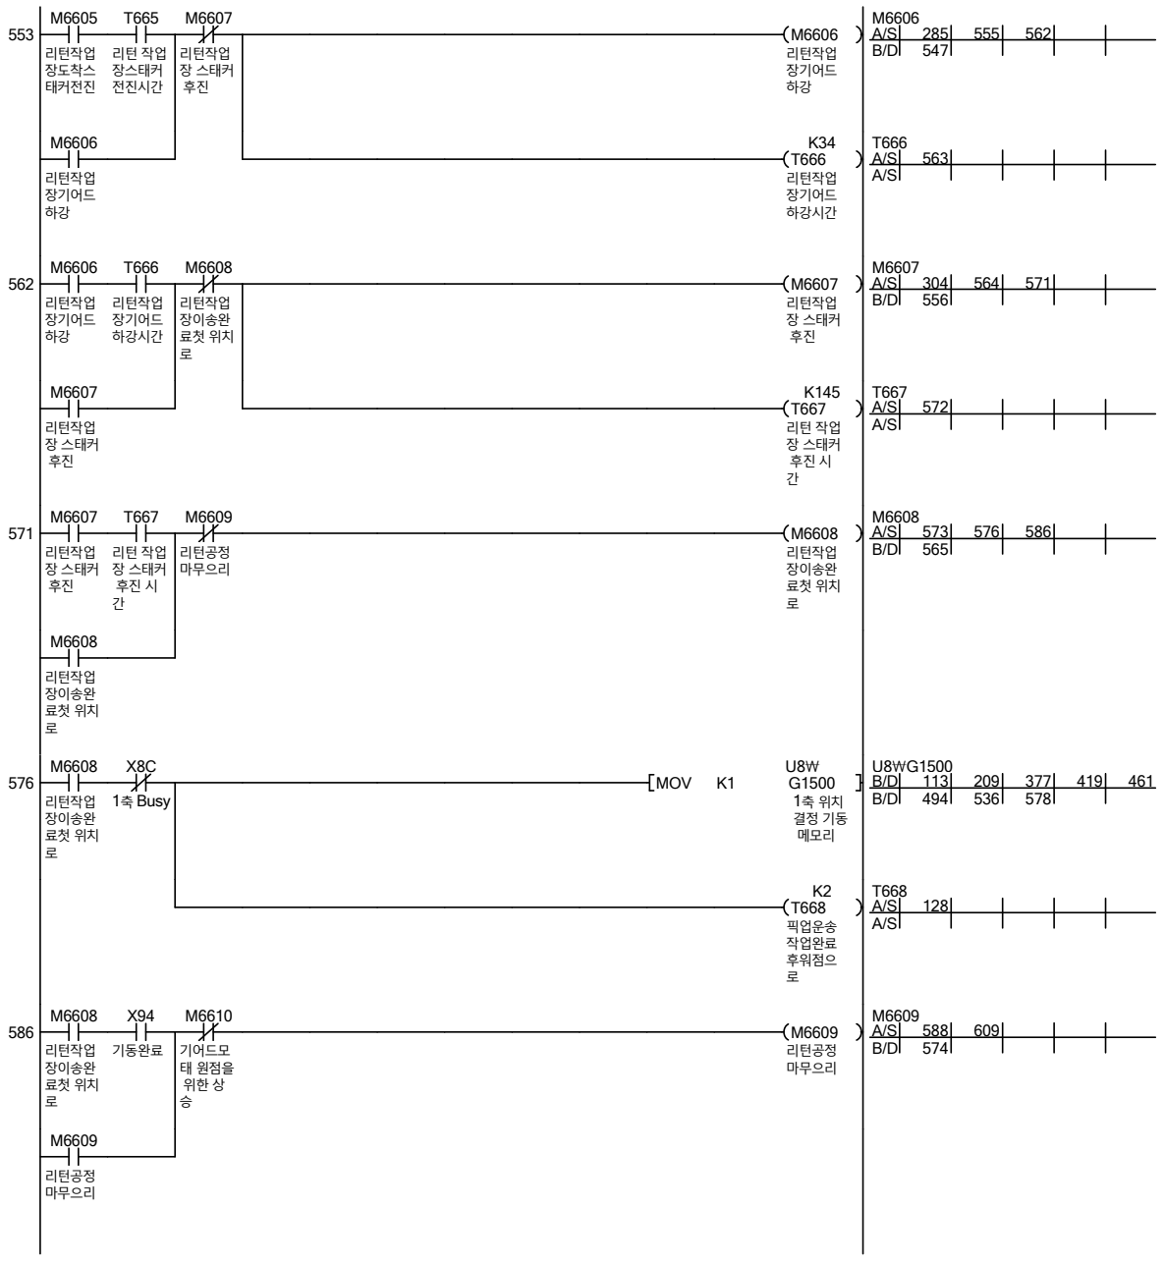
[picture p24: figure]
리턴작업 장도착스 태커전진; 리턴 작업 장스태커 전진시간; 리턴작업 장 스태커 후진; M6606 리턴작업 장기어드 하강; 리턴작업 장기어드 하강; K34 T666 리턴작업 장기어드 하강시간; 리턴작업 장기어드 하강시간; 리턴작업 장이송완 료첫 위치 로; M6607 리턴작업 장 스태커 후진; K145 T667 리턴 작업 장 스태커 후진 시 간; 리턴 작업 장 스태커 후진 시 간; 리턴공정 마무으리; M6608 리턴작업 장이송완 료첫 위치 로; 1 Busy 축; MOV; U8\ G1500 1 축 위치 결정 기동 메모리; K2 T668 픽업운송 작업완료 후워점으 로; 기동완료; 기어드모 태 원점을 위한 상 승; M6609 리턴공정 마무으리

56

Ladder | 10/2/2026

# Data Name : 9__SERVO

57

Device Comment | 10/2/2026

## Data Name : COMMENT

Device Name | Comment
M1 | 베이스 차상승 수동 1 ( )
M2 | 베이스 차하강 수동 1 ( )
M3 | 베이스 차상승 수동 2 ( )
M4 | 베이스 차하강 2
M5 | 베이스 차전진 3
M6 | 베이스 차후진 수동 3 ( )
M7 | 시트 공급전진 수동 A ( )
M8 | 시트 후진 수동 A ( )
M9 | 시트 공급전진 수동 B ( )
M10 | 시트 공급후진 수동 B ( )
M11 | 램프 공급전진 수동 A ( )
M12 | 램프 공급후진 수동 A ( )
M13 | 램프 공급전진 수동 B ( )
M14 | 램프 공급후진 수동 B ( )
M15 | 리턴스토퍼상승
M16 | 리턴스토퍼하강
M20 | START S/W
M22 | STOP S/W
M23 | RESET S/W
M24 | CREAR S/W
M30 | 메인 차컨베이어 On( 수동 1 )
M31 | 메인 차 컨베이어 On( 수동 2 )
M32 | 램프컨베이어 수동 On( )
M33 | 시트컨베이어 수동 On( )
M34 | 리턴 차컨베이어 1 On
M35 | 리턴 차컨에비어 2 On
M36 | 리턴 차컨에비어 3 On
M37 | 리턴 차컨베이어 4 On
M38 | 리턴 차컨베이어 5 On
M39 | 램프전원 수동 On( )
M40 | 램프스토퍼상승 수동 ( )
M41 | 램프스토퍼하강 수동 ( )
M42 | 시트스토퍼상승 수동 ( )
M43 | 시트스토퍼하강 수동 ( )
M44 | 스태커전진 수동 ( )
M45 | 스태커 후진 수동 ( )
M46 | 기어드모터 상승 수동 ( )
M47 | 기어트모터 하강 수동 ( )
M90 | SCADA ->PLC 생산요청
M103 | 램프 공급전진 A
M104 | 램프 공급후진 A
M105 | 램프 공급전진 B
M106 | 램프 공급후진 B
M107 | 시트 공급전진 A
M108 | 시트 공급후진 A
M109 | 시트 공급전진 B
M110 | 시트 공급후진 B
M115 | 베이스 차상승 1
M116 | 베이스 차하강 1
M117 | 베이스 차상승 2
M118 | 베이스 차하강 2
M119 | 베이스 상승 3
M120 | 베이스 차하강 3
M121 | 램프스토퍼상승
M122 | 램프스토퍼하강
M123 | 시트스토퍼상승
M124 | 시트스토퍼하강
M125 | 메인 차컨베이어 1 on
M126 | 메인 차컨베이어 1 OFF
M127 | 메인 차컨베이어 2 On
M128 | 메인 차컨베이어 2 Off
M131 | 램프컨베이어On
M132 | 램프컨베이어Off
M133 | 시트컨베이어On
M134 | 시트컨베이어Off
M135 | 리턴컨베이어 차1 On
M136 | 리턴 차컨베이어 1 Off
M137 | 리턴 차컨에비어 2 On
M138 | 리턴 차컨에비어 2 Off
M139 | 리턴 차컨에비어 3 On
M140 | 리턴 차컨에비어 3 Off
M141 | 리턴 차컨베이어 4 On
M142 | 리턴 차컨베이어 4 Off
58

Device Comment | 10/2/2026

## Data Name : COMMENT

Device Name | Comment
M143 | 리턴 차컨베이어 5 On
M144 | 리턴 차컨베이어 5 ff
M145 | 리턴하강
M146 | 리턴상승
M160 | 모터On
M161 | 모터Off
M162 | 앰프On
M163 | 앰프off
M230 | 스태커 전진
M231 | 스태커 후진
M232 | 램프전원On
M233 | 램프전원Off
M241 | 키어드모터 상승
M242 | 기어드모터하강
M248 | JOG속도변경
M249 | 조그 속도고속
M253 | 조그CW
M254 | 조그CCW
M255 | 원점 기동
M256 | 원점복귀
M258 | ServoErrorReset
M260 | 티칭모드
M261 | 티칭모드 On
M262 | 위치 저장
M270 | 기동모드
M271 | 기동모드 On
M272 | 해당위치 기동
M273 | 티칭정보 저장
M274 | 티칭정보저장신호
M275 | Flash ROM 쓰기중
M276 | Flsh ROM 쓰기 완료
M278 | 위치결정
M900 | 비전 미사용 4
M901 | 비전 필요데이터옮겨놓기 4
M998 | PLC 레디 스위치
M1001 | ROBOT_START_(1)
M1002 | ROBOT_RUNNING_(1)
M1003 | ROBOT_FINISH_(1)
M1005 | ROBOT_READY_(1)
M1011 | ROBOT_START_(2)
M1012 | ROBOT_RUNNING_(2)
M1013 | ROBOT_FINISH_(2)
M1015 | ROBOT_READY_(2)
M1021 | ROBOT_START_(3)
M1022 | ROBOT_RUNNING_(3)
M1023 | ROBOT_FINISH_(3)
M1025 | ROBOT_READY_(3)
M1031 | ROBOT_START_(4)
M1032 | ROBOT_RUNNING_(4)
M1033 | ROBOT_FINISH_(4)
M1034 | ROBOT_ERROR_(4)
M1035 | ROBOT_READY_(4)
M1036 | ROBOT_FINISH(B)_(4)
M1037 | ROBOT_SRART(B)_(4)
M1101 | VISION1_START
M1103 | VISION1_FINISH
M1104 | VISION1_NG
M1105 | VISION1_ERROR
M1111 | VISION2_START
M1113 | VISION2_FINISH( ) 양품
M1114 | VISION2_NG
M1115 | VISION2_ERROR
M1121 | VISION3_START
M1123 | VISION3_FINISH
M1124 | VISION3_NG
M1125 | VISION3_ERROR
M1131 | VISION4_START
M1133 | VISION4_FINISH
M1134 | VISION4_NG
M1135 | VISION4_ERROR
M1600 | 앰프On
M1601 | 모터On
M2001 | 램프라인초기상태확인
59

Device Comment | 10/2/2026

## Data Name : COMMENT

Device Name | Comment
M2002 | 샤시라인 초기상태확인 1
M2003 | 샤시라인 초기상태확인 2
M2004 | 시트라인초기상태확인
M2005 | 초기상태확인완료
M2006 | 리턴라인초기상태확인
M2011 | 램프라인리셋
M2012 | 샤시라인 리셋 1
M2013 | 샤시라인 리셋 2
M2014 | 시트라인리셋
M2016 | 리턴라인리셋
M2100 | 자동모드준비완료
M2101 | 자동모드기동시작
M3000 | 샤시공급 로봇 _ 4
M3001 | 샤시램프조립위치로컨베이어On
M3002 | 램프조립 로봇 _ 1
M3003 | 샤시램프조립완료스토퍼상승
M3004 | 샤시시트조립위치로컨베이어On
M3005 | 첫번째시트조립시작
M3006 | 두번째시트조립시작
M3007 | 샤시시트스토퍼상승
M3008 | 샤시최종비전검사로컨베이어1On
M3009 | 샤시시트스토퍼하강
M3010 | 샤시컨베이어 완료 1
M3011 | 샤시램프스토퍼하강
M3020 | 샤시최종비전으로컨베이어2On
M3021 | 창고전진컨베이어 램프전원 On off
M3022 | 최종신린더 후진
M3023 | 창고 재활용공정진행중이송완료 ,
M3030 | Vision3양품제품
M3031 | Vison3불량품
M3040 | 상부조립공정중
M3050 | 최종비전에러 전체리셋 ,
M3100 | 샤시 공급 완료
M3121 | 재활용전진컨베이어 램프전원 On Off
M3300 | 샤시램프조립완료
M4000 | 램프 공급전진 A
M4001 | 램프 공급후진 A
M4002 | 램프 공급전진 B
M4003 | 램프 공급후진 B
M4004 | 램프공급컨베이어On
M4005 | 불량램프반출스퍼상승컨베이어on
M4006 | 램프반출완료
M4007 | 램프지그배출스토퍼상승컨베이어on
M4008 | 램프지그 반출 완료
M4009 | 램프조립위치로컨베이어On
M4100 | 램프라인가동
M4200 | 램프비전위치근접컨베이어
M5000 | 시트 공급 전진 A
M5001 | 시트 공급후진 A
M5002 | 시트 공급전진 B
M5003 | 시트 공급후진 B
M5004 | 시트공급컨베이어On
M5005 | 불량시트배출스토퍼상승컨베이어on
M5006 | 시트반출 완료
M5007 | 시트지그배출스토퍼상승컨베이어on
M5008 | 시트지그배출완료
M5009 | 시트조립위치로컨베이어on
M5100 | 시트라인 가동
M5110 | 시트 공정 완료
M5200 | 시트리턴컨베이어1On
M5201 | 리턴 번컨베이어 2 On
M5202 | 리턴컨베이어1Off,3On
M5203 | 리턴컨베이어4On
M5204 | 리턴컨베잉어 비전 3off,4off 4
M5205 | 리턴스토퍼상승 컨베이어 , 4On
M5206 | 리턴컨베비어5On
M5208 | 지그배출완료
M5300 | 리턴컨베이어4On
M5301 | 리턴컨베이어4off
M5302 | 리턴제품재공급로봇 시작 4
M5303 | 제품제공급 완료
M5400 | 램프리턴컨베이어1On
M5500 | 시트비전위치 근접
60

Device Comment | 10/2/2026

## Data Name : COMMENT

Device Name | Comment
M5555 | 양품창고공정시작
M6000 | 픽업위피로
M6001 | 픽업위치 스태커 전진
M6002 | 픽업 기어드모터상승
M6003 | 제품픽업스태커모터 후진
M6004 | 1 번창고 위치로 처음
M6005 | 1 번창고저장을위한스태커 전진
M6006 | 1번창고저장기어드하강
M6007 | 스태커 번창저장후 후진 1
M6008 | 차음창고적재완료후 원점복귀
M6009 | 창고공정마무으리
M6200 | QD75 SON 준비완료
M6600 | 불량 픽업위치로
M6601 | 불량픽업스태커전진
M6602 | 불량픽업기어드상승
M6603 | 불량픽업스태커후진
M6604 | 리턴작업장으로
M6605 | 리턴작업장도착스태커전진
M6606 | 리턴작업장기어드하강
M6607 | 리턴작업장 스태커 후진
M6608 | 리턴작업장이송완료첫 위치로
M6609 | 리턴공정마무으리
M6610 | 기어드모태 원점을 위한 상승
M6611 | 기어드모터원점을 위한 하강
M6612 | 기어드모터원점도착
M6666 | 불량품창고공정시작
M7000 | 수동모드
M7001 | 기어드 원점 위한 상승 수동 ( )
M7002 | 기어드 원점을 위한 하강 수동 ( )
M7011 | 기어드 원점 위한 상승 수동 ( )
M7012 | 기어드 원점을 위한 하강 수동 ( )
M8000 | 수동 전체 전원
M8001 | 서보 미상정지
SM400 | 상시ON
SM412 | 0.5s점멸
X0 | 샤시공급 센서
X1 | 샤시램프조립위치
X2 | 샤시시트조립위치
X4 | 샤시최종비전센서
X5 | 시트 제품감지 A
X6 | 시트 제품감지 B
X7 | 시트로봇위치센서
X8 | 램프조립위치센서
X0A | 램프 제품감지 A
X0B | 램프 제품감지 B
X0C | 리턴 컨베이어센서 1
X0E | 리턴 번 센서 2
X0F | 리턴 번센서 4
X10 | 시트비전위치센서
X13 | 샤시램프조립스토퍼하강센서
X15 | 램프스토퍼하강센서
X17 | 샤시최종실린더후진센서
X19 | 시트스토퍼하강센서
X1A | 샤시시트스토퍼하강
X1D | 램프비전감지센서
X23 | 램프 공급후진센서 A
X25 | 램프 공급후진센서 B
X27 | 시트 공급후진센서 A
X29 | 시트 공급후진센서 B
X2B | 리턴스토퍼하강센서
X30 | Hi Limit
X31 | Home Limit
X32 | Low Limit
X3E | S/S( / ) 수동 자동
X3F | 비상 스위치
X80 | QD75 READY
X81 | 버퍼메모리접근가능
X88 | QD75에러
X8C | 1 Busy 축
X90 | 기동시작
X94 | 기동완료
Y40 | 램프 공급 전진 A
Y41 | 램프 공급 후진 A
61

Device Comment | 10/2/2026

## Data Name : COMMENT

Device Name | Comment
Y42 | 램프 공급 전진 B
Y43 | 램프 공급 후진 B
Y45 | 램프 스토퍼 상승
Y47 | M1 1 모터
Y48 | M2 2 모터
Y4A | 시트 공급 전진 A
Y4B | 시트 공급 후진 A
Y4C | 시트 공급 전진 B
Y4D | 시트 공급 후진 B
Y4E | 시트 스토퍼 하강
Y4F | 시트 스토퍼 상승
Y50 | 최종실린더 후진
Y51 | 최종실린더전진
Y52 | S1-4 모터
Y53 | R1-5 모터
Y54 | R2-6 모터
Y55 | R3-7 모터
Y56 | R4-8 모터
Y57 | R5-9 모터
Y58 | L1-10 모터
Y59 | 리턴 스토퍼 하강
Y5A | 리턴 스토퍼 상승
Y5F | 램프 ON
Y60 | 앰프On
Y61 | 모터On
Y65 | 램프스토퍼하강
Y68 | 기어드모터상승
Y69 | 기어드모터하강
Y6B | 스태커 전진
Y6C | 스태커 후진
Y71 | 샤시스토퍼하강
Y72 | 샤시스토퍼상승
Y74 | 샤시스토퍼 하강 2
Y75 | 샤시스토퍼 상승 2
Y80 | PLC READY
Y88 | 조그 운전 CW
Y89 | 조그 운전 CCW
Y90 | 위치결정 시작
D0 | 생산요청 번호
D200 | 서보위치번호 입력 ( )
D212 | 서보위치번호 시작번호 맞추기
D214 | 서보위치번호 시작번호 자릿수 맞
D800 | 현재속도
D806 | 축에러
D807 | 축경고
D1010 | 현재시트생산주문번호
D1011 | ROBOT2_TARGET_COUNT
D1012 | ROBOT2_FINISH_COUNT
D1101 | VISION1_PRODUCT
D1111 | VISION2_PRODUCT
D1121 | VISION3_PRODUCT
D1131 | VISION4_CLASS_RESULT
D2004 | 위치결정데이터 번지령속도 1
D2006 | 이동량 위치결정어드레스 /
D9131 | Vision4_fake_Result_lamp
D9132 | Vision4_fake_Result_seat
T256 | 원점 복귀
T271 | 위치결정기동
T274 | 티칭저장
T302 | 샤시램프조립위치도착컨베이어off
T303 | 샤시램프스토퍼상승확인
T304 | 샤시시트조립위치도착
T307 | 샤시시트스토퍼상승확인
T308 | 샤시컨베이어 최종 1 off
T320 | 제품최종검사시작램프 컨베이어 On Of
T321 | 컨베이어 상부조립시작 off,
T331 | 컨베이어 재활용공정 시작 off,
T400 | 램프 공급전진확인 A
T402 | 램프 공급전진확인 B
T404 | 램프 비전위치도착컨베이어 Off
T405 | 램프스토퍼하강 컨베이어 , off
T406 | 램프반출완료자기유지킬
T407 | 램프스토퍼하강 컨베이어 , off
62

Device Comment | 10/2/2026

## Data Name : COMMENT

Device Name | Comment
T408 | 램프지그반출완료자기유지킬
T409 | 램프조립위치도착컨베이어Off
T500 | 시트 공급전진확인 A
T502 | 시트 공급전진확인 B
T504 | 시트비전위치도착컨베이어off
T505 | 시트스토퍼하강컨베이어Off
T506 | 시트배출확인자기유지킬
T507 | 시트지그배출완료스토퍼컨베이어Of
T508 | 시트지그배출완료자기유지킬
T509 | 시트조립위한컨베이어off
T522 | 리턴컨베이어4On
T525 | 리턴컨베이어5On
T526 | 리턴컨베이어 스토퍼하강 4off,
T528 | 리턴컨베이어5off
T530 | 리턴컨베이어4Off
T600 | 1번위치로픽업위치기동
T601 | 서보 픽업 위치 완료 딜레이
T602 | 픽업기어드모터 상승시간
T603 | 제품픽업스태커모터후진시간
T604 | 1 번창고 위치로 기동
T605 | 1 번창고처음도착후 스태커 전진
T606 | 기어드 하강시간
T607 | 창고 적재후 스태커 후진
T608 | 창고적재완료후원점복귀
T660 | 불량픽업위치
T661 | 불량픽업스태커전진시간
T662 | 불량픽업스태커상승시간
T663 | 불량픿업스태커후진시간
T664 | 리턴 작업장으로
T665 | 리턴 작업장스태커전진시간
T666 | 리턴작업장기어드하강시간
T667 | 리턴 작업장 스태커 후진 시간
T668 | 픽업운송작업완료후워점으로
T900 | 비전 임의 검사시간 4
P0 | 샤시공급시작
P1 | 샤시 차 공급완료 램프조립 1 _
P2 | 램프조립완료
P3 | 샤시 차공급완료 시트조립 2 _
P4 | 시트조립완료 로봇 _ _2
P5 | 샤시 차공급완료 3
U8\G800 | 현재 속도
U8\G806 | 축에러
U8\G807 | 축 경고
U8\G1500 | 1 축 위치결정 기동 메모리
U8\G1502 | Servo error reset
U8\G1518 | 조그속도
U8\G1900 | Flash ROM Write
U8\G2000 | 위치결정 식별자
U8\G2004 | 위치결정데이터 번지령속도 1
U8\G2006 | 이동량 위치결정어드레스 /

63

Device List | 10/2/2026

## Data Name : Device List

## Find In:(Entire project) Find What:Used Device (Contact & Coil) Print Range:Whole Range

## *:in use, (counts): the number of coil uses

Device | Contact | Coil (counts) | Parameter | Comment
M1 | * | *( 1) | | 베이스 차상승 수동 1 ( )
M2 | * | *( 1) | | 베이스 차하강 수동 1 ( )
M3 | * | *( 1) | | 베이스 차상승 수동 2 ( )
M4 | * | *( 1) | | 베이스 차하강 2
M5 | * | *( 1) | | 베이스 차전진 3
M6 | * | *( 1) | | 베이스 차후진 수동 3 ( )
M7 | * | *( 1) | | 시트 공급전진 수동 A ( )
M8 | * | *( 1) | | 시트 후진 수동 A ( )
M9 | * | *( 1) | | 시트 공급전진 수동 B ( )
M10 | * | *( 1) | | 시트 공급후진 수동 B ( )
M11 | * | *( 1) | | 램프 공급전진 수동 A ( )
M12 | * | *( 1) | | 램프 공급후진 수동 A ( )
M13 | * | *( 1) | | 램프 공급전진 수동 B ( )
M14 | * | *( 1) | | 램프 공급후진 수동 B ( )
M15 | * | *( 1) | | 리턴스토퍼상승
M16 | * | *( 1) | | 리턴스토퍼하강
M30 | * | *( 1) | | 메인 차컨베이어 On( 수동 1 )
M31 | * | *( 1) | | 메인 차 컨베이어 On( 수동 2 )
M32 | * | *( 1) | | 램프컨베이어 수동 On( )
M33 | * | *( 1) | | 시트컨베이어 수동 On( )
M34 | * | *( 1) | | 리턴 차컨베이어 1 On
M35 | * | *( 1) | | 리턴 차컨에비어 2 On
M36 | * | *( 1) | | 리턴 차컨에비어 3 On
M37 | * | *( 1) | | 리턴 차컨베이어 4 On
M38 | * | *( 1) | | 리턴 차컨베이어 5 On
M39 | * | *( 1) | | 램프전원 수동 On( )
M40 | * | *( 1) | | 램프스토퍼상승 수동 ( )
M41 | * | *( 1) | | 램프스토퍼하강 수동 ( )
M42 | * | *( 1) | | 시트스토퍼상승 수동 ( )
M43 | * | *( 1) | | 시트스토퍼하강 수동 ( )
M44 | * | *( 1) | | 스태커전진 수동 ( )
M45 | * | *( 1) | | 스태커 후진 수동 ( )
M46 | * | *( 1) | | 기어드모터 상승 수동 ( )
M47 | * | *( 1) | | 기어트모터 하강 수동 ( )
M249 | * | *( 1) | | 조그 속도고속
M256 | * | *( 1) | | 원점복귀
M261 | * | *( 1) | | 티칭모드 On
M271 | * | *( 1) | | 기동모드 On
M274 | * | *( 1) | | 티칭정보저장신호
M275 | * | *( 2) | | Flash ROM 쓰기중
M278 | * | *( 1) | | 위치결정

64

Device List | 10/2/2026

## Data Name : Device List

## Find In:(Entire project) Find What:Used Device (Contact & Coil) Print Range:Whole Range

## *:in use, (counts): the number of coil uses

Device | Contact | Coil (counts) | Parameter | Comment
M901 | * | *( 1) | | 비전 필요데이터옮겨놓기 4
M1103 | * | *( 1) | | VISION1_FINISH
M1104 | * | *( 1) | | VISION1_NG
M1113 | * | *( 1) | | VISION2_FINISH( ) 양품
M1114 | * | *( 1) | | VISION2_NG
M1123 | * | *( 1) | | VISION3_FINISH
M1124 | * | *( 1) | | VISION3_NG
M1133 | * | *( 1) | | VISION4_FINISH
M1135 | * | *( 1) | | VISION4_ERROR
M1600 | * | *( 1) | | 앰프On
M1601 | * | *( 1) | | 모터On
M2001 | * | *( 1) | | 램프라인초기상태확인
M2002 | * | *( 1) | | 샤시라인 초기상태확인 1
M2003 | * | *( 1) | | 샤시라인 초기상태확인 2
M2004 | * | *( 1) | | 시트라인초기상태확인
M2005 | * | *( 1) | | 초기상태확인완료
M2006 | * | *( 1) | | 리턴라인초기상태확인
M2011 | * | *( 1) | | 램프라인리셋
M2012 | * | *( 1) | | 샤시라인 리셋 1
M2013 | * | *( 1) | | 샤시라인 리셋 2
M2014 | * | *( 1) | | 시트라인리셋
M2016 | * | *( 1) | | 리턴라인리셋
M2100 | * | *( 1) | | 자동모드준비완료
M3000 | * | *( 1) | | 샤시공급 로봇 _ 4
M3001 | * | *( 1) | | 샤시램프조립위치로컨베이어On
M3002 | * | *( 1) | | 램프조립 로봇 _ 1
M3003 | * | *( 1) | | 샤시램프조립완료스토퍼상승
M3004 | * | *( 1) | | 샤시시트조립위치로컨베이어On
M3005 | * | *( 1) | | 첫번째시트조립시작
M3006 | * | *( 1) | | 두번째시트조립시작
M3007 | * | *( 1) | | 샤시시트스토퍼상승
M3008 | * | *( 1) | | 샤시최종비전검사로컨베이어1On
M3009 | * | *( 1) | | 샤시시트스토퍼하강
M3010 | * | *( 1) | | 샤시컨베이어 완료 1
M3011 | * | *( 1) | | 샤시램프스토퍼하강
M3020 | * | *( 1) | | 샤시최종비전으로컨베이어2On
M3021 | * | *( 1) | | 창고전진컨베이어 램프전원 On off
M3022 | * | *( 1) | | 최종신린더 후진
M3023 | * | *( 1) | | 창고 재활용공정진행중이송완료 ,
M3040 | * | *( 1) | | 상부조립공정중
M3050 | * | *( 1) | | 최종비전에러 전체리셋 ,

65

Device List | 10/2/2026

## Data Name : Device List

## Find In:(Entire project) Find What:Used Device (Contact & Coil) Print Range:Whole Range

## *:in use, (counts): the number of coil uses

Device | Contact | Coil (counts) | Parameter | Comment
M3100 | * | *( 1) | | 샤시 공급 완료
M3121 | * | *( 1) | | 재활용전진컨베이어 램프전원 On Off
M3300 | * | *( 1) | | 샤시램프조립완료
M4000 | * | *( 1) | | 램프 공급전진 A
M4001 | * | *( 1) | | 램프 공급후진 A
M4002 | * | *( 1) | | 램프 공급전진 B
M4003 | * | *( 1) | | 램프 공급후진 B
M4004 | * | *( 1) | | 램프공급컨베이어On
M4005 | * | *( 1) | | 불량램프반출스퍼상승컨베이어on
M4006 | * | *( 1) | | 램프반출완료
M4007 | * | *( 1) | | 램프지그배출스토퍼상승컨베이어on
M4008 | * | *( 1) | | 램프지그 반출 완료
M4009 | * | *( 1) | | 램프조립위치로컨베이어On
M4100 | * | *( 1) | | 램프라인가동
M4200 | * | *( 1) | | 램프비전위치근접컨베이어
M5000 | * | *( 1) | | 시트 공급 전진 A
M5001 | * | *( 1) | | 시트 공급후진 A
M5002 | * | *( 1) | | 시트 공급전진 B
M5003 | * | *( 1) | | 시트 공급후진 B
M5004 | * | *( 1) | | 시트공급컨베이어On
M5005 | * | *( 1) | | 불량시트배출스토퍼상승컨베이어on
M5006 | * | *( 1) | | 시트반출 완료
M5007 | * | *( 1) | | 시트지그배출스토퍼상승컨베이어on
M5008 | * | *( 1) | | 시트지그배출완료
M5009 | * | *( 1) | | 시트조립위치로컨베이어on
M5100 | * | *( 1) | | 시트라인 가동
M5200 | * | *( 1) | | 시트리턴컨베이어1On
M5201 | * | *( 1) | | 리턴 번컨베이어 2 On
M5202 | * | *( 1) | | 리턴컨베이어1Off,3On
M5203 | * | *( 1) | | 리턴컨베이어4On
M5204 | * | *( 1) | | 리턴컨베잉어 비전 3off,4off 4
M5205 | * | *( 1) | | 리턴스토퍼상승 컨베이어 , 4On
M5206 | * | *( 1) | | 리턴컨베비어5On
M5208 | * | *( 1) | | 지그배출완료
M5300 | * | *( 1) | | 리턴컨베이어4On
M5301 | * | *( 1) | | 리턴컨베이어4off
M5302 | * | *( 1) | | 리턴제품재공급로봇 시작 4
M5303 | * | *( 1) | | 제품제공급 완료
M5400 | * | *( 1) | | 램프리턴컨베이어1On
M5500 | * | *( 1) | | 시트비전위치 근접
M5555 | * | *( 1) | | 양품창고공정시작

66

Device List | 10/2/2026

## Data Name : Device List

## Find In:(Entire project) Find What:Used Device (Contact & Coil) Print Range:Whole Range

## *:in use, (counts): the number of coil uses

Device | Contact | Coil (counts) | Parameter | Comment
M6000 | * | *( 1) | | 픽업위피로
M6001 | * | *( 1) | | 픽업위치 스태커 전진
M6002 | * | *( 1) | | 픽업 기어드모터상승
M6003 | * | *( 1) | | 제품픽업스태커모터 후진
M6004 | * | *( 1) | | 1 번창고 위치로 처음
M6005 | * | *( 1) | | 1 번창고저장을위한스태커 전진
M6006 | * | *( 1) | | 1번창고저장기어드하강
M6007 | * | *( 1) | | 스태커 번창저장후 후진 1
M6008 | * | *( 1) | | 차음창고적재완료후 원점복귀
M6009 | * | *( 1) | | 창고공정마무으리
M6200 | * | *( 1) | | QD75 SON 준비완료
M6600 | * | *( 1) | | 불량 픽업위치로
M6601 | * | *( 1) | | 불량픽업스태커전진
M6602 | * | *( 1) | | 불량픽업기어드상승
M6603 | * | *( 1) | | 불량픽업스태커후진
M6604 | * | *( 1) | | 리턴작업장으로
M6605 | * | *( 1) | | 리턴작업장도착스태커전진
M6606 | * | *( 1) | | 리턴작업장기어드하강
M6607 | * | *( 1) | | 리턴작업장 스태커 후진
M6608 | * | *( 1) | | 리턴작업장이송완료첫 위치로
M6609 | * | *( 1) | | 리턴공정마무으리
M6610 | * | *( 1) | | 기어드모태 원점을 위한 상승
M6611 | * | *( 1) | | 기어드모터원점을 위한 하강
M6612 | * | *( 1) | | 기어드모터원점도착
M6666 | * | *( 1) | | 불량품창고공정시작
M7000 | * | *( 1) | | 수동모드
M7001 | * | *( 1) | | 기어드 원점 위한 상승 수동 ( )
M7002 | * | *( 1) | | 기어드 원점을 위한 하강 수동 ( )
Y80 | * | *( 1) | | PLC READY
D212 | * | *( 1) | | 서보위치번호 시작번호 맞추기
D214 | * | *( 1) | | 서보위치번호 시작번호 자릿수 맞
D215 | * | *( 1)
D1010 | * | *( 3) | | 현재시트생산주문번호
D1011 | * | *( 4) | | ROBOT2_TARGET_COUNT
D1012 | * | *( 3) | | ROBOT2_FINISH_COUNT
D1101 | * | *( 3) | | VISION1_PRODUCT
D1111 | * | *( 3) | | VISION2_PRODUCT
D1121 | * | *( 4) | | VISION3_PRODUCT
D1131 | * | *( 9) | | VISION4_CLASS_RESULT
T256 | * | *( 1) | | 원점 복귀
T271 | * | *( 1) | | 위치결정기동

67

Device List | 10/2/2026

## Data Name : Device List

## Find In:(Entire project) Find What:Used Device (Contact & Coil) Print Range:Whole Range

## *:in use, (counts): the number of coil uses

Device | Contact | Coil (counts) | Parameter | Comment
T274 | * | *( 1) | | 티칭저장
T302 | * | *( 1) | | 샤시램프조립위치도착컨베이어off
T303 | * | *( 1) | | 샤시램프스토퍼상승확인
T304 | * | *( 1) | | 샤시시트조립위치도착
T307 | * | *( 1) | | 샤시시트스토퍼상승확인
T308 | * | *( 1) | | 샤시컨베이어 최종 1 off
T320 | * | *( 1) | | 제품최종검사시작램프 컨베이어 On Of
T321 | * | *( 1) | | 컨베이어 상부조립시작 off,
T323 | * | *( 1)
T331 | * | *( 1) | | 컨베이어 재활용공정 시작 off,
T340 | * | *( 1)
T350 | * | *( 1)
T400 | * | *( 1) | | 램프 공급전진확인 A
T402 | * | *( 1) | | 램프 공급전진확인 B
T404 | * | *( 1) | | 램프 비전위치도착컨베이어 Off
T405 | * | *( 1) | | 램프스토퍼하강 컨베이어 , off
T406 | * | *( 1) | | 램프반출완료자기유지킬
T407 | * | *( 1) | | 램프스토퍼하강 컨베이어 , off
T408 | * | *( 1) | | 램프지그반출완료자기유지킬
T409 | * | *( 1) | | 램프조립위치도착컨베이어Off
T500 | * | *( 1) | | 시트 공급전진확인 A
T502 | * | *( 1) | | 시트 공급전진확인 B
T504 | * | *( 1) | | 시트비전위치도착컨베이어off
T505 | * | *( 1) | | 시트스토퍼하강컨베이어Off
T506 | * | *( 1) | | 시트배출확인자기유지킬
T507 | * | *( 1) | | 시트지그배출완료스토퍼컨베이어Of
T508 | * | *( 1) | | 시트지그배출완료자기유지킬
T509 | * | *( 1) | | 시트조립위한컨베이어off
T522 | * | *( 1) | | 리턴컨베이어4On
T525 | * | *( 1) | | 리턴컨베이어5On
T526 | * | *( 1) | | 리턴컨베이어 스토퍼하강 4off,
T528 | * | *( 1) | | 리턴컨베이어5off
T529 | * | *( 1)
T530 | * | *( 1) | | 리턴컨베이어4Off
T533 | * | *( 1)
T600 | * | *( 1) | | 1번위치로픽업위치기동
T601 | * | *( 1) | | 서보 픽업 위치 완료 딜레이
T602 | * | *( 1) | | 픽업기어드모터 상승시간
T603 | * | *( 1) | | 제품픽업스태커모터후진시간
T604 | * | *( 1) | | 1 번창고 위치로 기동
T605 | * | *( 1) | | 1 번창고처음도착후 스태커 전진

68

Device List | 10/2/2026

## Data Name : Device List

## Find In:(Entire project) Find What:Used Device (Contact & Coil) Print Range:Whole Range

## *:in use, (counts): the number of coil uses

Device | Contact | Coil (counts) | Parameter | Comment
T606 | * | *( 1) | | 기어드 하강시간
T607 | * | *( 1) | | 창고 적재후 스태커 후진
T608 | * | *( 1) | | 창고적재완료후원점복귀
T612 | * | *( 1)
T660 | * | *( 1) | | 불량픽업위치
T661 | * | *( 1) | | 불량픽업스태커전진시간
T662 | * | *( 1) | | 불량픽업스태커상승시간
T663 | * | *( 1) | | 불량픿업스태커후진시간
T664 | * | *( 1) | | 리턴 작업장으로
T665 | * | *( 1) | | 리턴 작업장스태커전진시간
T666 | * | *( 1) | | 리턴작업장기어드하강시간
T667 | * | *( 1) | | 리턴 작업장 스태커 후진 시간
T668 | * | *( 1) | | 픽업운송작업완료후워점으로
T900 | * | *( 1) | | 비전 임의 검사시간 4
Z1 | * | *( 4)
U8 | * | *( 15)

69

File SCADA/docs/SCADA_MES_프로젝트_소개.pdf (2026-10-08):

# 설비 모니터링에서 생산 이력까지

CIMON SCADA · KEPServerEX · OPC UA · MySQL · Python Web MES

SCADA; 설비·알람·트렌드 모니터링; 데이터 수집; 최신 상태와 변경 이력 저장; MES; 제품별 작업·검사·재고 기록; NG 처리와 승인 보고서

TEAM 2 | SCADA · MES | 공개용 자료 | 2026-10-08 | 1

## PLC·Dobot·Vision을 연결한 조립 공정에서 생산 지시, 설비 상태, 제품별 작업 기록을 함께 관리하

는 팀 프로젝트입니다.

SCADA 생산 DB → MES: 주문·상품·생산 이력 읽기 연동 구현

MES → SCADA 재생산 명령·ACK, MES → ERP 전송: 아직 미연결

공개 준비 검증: 코드·문서·화면 확인. 실제 설비 운전 재시험은 수행하지 않음

# 데이터와 제어의 연결 구조

생산 제어, 설비 상태 수집, 작업자 확인 기록을 구분합니다.

## 생산 제어

CIMON SCADA → KEPServerEX → PLC → Dobot / Vision

## 설비 상태

PLC / Dobot / Vision → KEPServer OPC UA → 수집기 → MySQL → MES

## 주문 가져오기

SCADA smart_factory DB → 읽기 어댑터 → MES 주문·제품 기록

## 작업 이력

작업자 확인 → MES 공정·재고·승인 기록 → PDF 보고서

태그 구성: 로봇 57 + Vision 24 + 주문 21 + 라인 상태 4 = 106

250ms는 OPC UA 구독 요청값. 통신 단절 중 발생한 짧은 펄스의 완전 복구를 보장하지 않음

제품별 공정은 작업자 확인 기록. 설비 신호와 제품 추적 ID의 자동 연결은 미구현

# SCADA: 공정과 생산 상태를 한 화면에

원본 화면 캡처 | 현재 운전 상태를 뜻하지 않음


라인 레이아웃과 설비 상태

Vision 검사 상태 요약

생산 주문·수량·진행률

로봇 모니터·알람·트렌드

최종 구성 문서 기준
프로그램 번호 D0
START M90 / 500ms
정상 완료 M1023
최종 검사 NG M1124

CIMON 원본과 KEPServer 설정은 비공개 보관. 공개 ZIP은 보조 코드·테이블 구조 선별본입니다.

# MES: 제품별 작업 이력과 검사 기록

학습용 웹 시스템 | 작업자 확인으로 제품별 공정을 기록


공급 → Vision1 → 로봇1 → Vision2 → 로봇2 → 로봇3 → Vision3 → 완료창고

설비 상태는 DB에서 조회하고 제품별 진행은 작업자가 확인

검사 승인과 PDF 생성 구현. 관리자 승인/자동 승인 기록을 포 함

재고 일부는 작업자 입력. 실제 창고 수량을 자동 센싱하는 구 조는 아님

TEST/PRODUCTION은 저장 데이터 분류이며 PLC 운전 모드를 변경하지 않음

작업자/관리자 화면 선택은 로그인 인증 기능이 아님

# 주문 가져오기와 NG 재생산 큐


읽기 연동 구현과 생산 명령 미연결 상태를 함께 표시

SCADA 주문 가져오기
원본 주문 ID를 보존해 중복 가져오기를 방지하고 기존 주문을 TEST로 분 류합니다.

NG 재생산
MES 내부 큐·outbox는 생성됩니다. SCADA로 보내는 명령과 실제 생산 시 작 ACK는 미연결입니다.

기존 완료 주문을 가져왔다고 해서 과거 공정 확인·승인·창고 재고가 자동으로 생성되는 것은 아닙니다.

# 담당 범위와 포트폴리오 근거

팀 산출물과 본인 작업의 연결 지점을 구분합니다.

## 팀 산출물

SCADA: CIMON 화면·생산 제어 구성과 KEPServer·DB 운영 자료

MES: 김동진 프로젝트 산출물의 웹 MES 및 OPC UA 데이터 수집 코드

Vision 알고리즘: 팀원 담당. 본인의 Dobot 제어 개발과 구분

## 본인 작업과 연결되는 지점

Dobot 통합 제어와 OPC UA 태그를 통한 생산 공정 연계

SCADA의 로봇 상태 표시와 MES의 설비 상태 수집이 Dobot 제어와 연결됨

SCADA/MES 자체 개발·장비 시험을 개인 성과로 주장하지 않으며, 직접 담당한 추가 작업은 증빙 후 명시

제공 자료: 공개용 소스 ZIP · 주요 화면 · 구축/운영 안내 · DB 구조/연동 설명
계정·운영 DB·로그·개인 PC 설정 및 원본 바이너리는 공개본에서 제외했습니다.

근거: SCADA 최종 재구축 매뉴얼, project-mes 코드·README, SCADA_MES_INTEGRATION, SCADA_PIPELINE 후속 갱신, data_collect_all.

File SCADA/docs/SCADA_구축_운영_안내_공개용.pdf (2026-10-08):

# SCADA 구축·운영 안내

계정과 내부 주소를 제외한 공개용 요약 | 전체 복원 매뉴얼 아님
TEAM 2 | SCADA · MES | 공개용 자료 | 2026-10-08 | 1

원본 문서 환경: CIMON SCADA 3.90 / KEPServerEX 6.11.718.0 / MySQL 8.0.46

CIMON 화면: 메인·라인·로봇·Vision·알람·트렌드·시스템

CIMON과 KEPServer 태그 연결, MySQL smart_factory, 32-bit ODBC Unicode Driver 구성

새 PC 복원에는 정식 프로그램, 비공개 원본 프로젝트, 현장 태그·통신 설정이 필요

공개 ZIP: Vision 4채널 MJPEG 중계, 로봇 TCP 연결 감시, smart_factory 7개 테이블 정의

CIMON PGX/SCX/PRJ 및 KEPServer OPF 원본은 공개 ZIP에 포함하지 않음

원본의 Python order/production *_test 및 Quick Client 예제는 시험 자료입니다. 최종 CIMON 생산 제어를 대신하는 검증된 실행 코드로 표시하지 않습니다.

기존 원본 수정 없음. 공개본에서 운영 DB와 실제 계정·내부 IP·사용자 경로 제외. 실제 설비 연결/생산 운전 재검증 없음.

# 생산 제어 신호와 운영 확인

최종 재구축 매뉴얼 기준. 실제 연결 전 현장 I/O와 대조해야 합니다.

TEAM 2 | SCADA · MES | 공개용 자료 | 2026-10-08 | 2

프로그램 선택: ORDER.PLC_PROGRAM_NO → PLC_Program_No → D0

기동: ORDER.PLC_START → M90, 500ms 펄스

정상 완료: ROBOT.ROBOT_FINISH_3 / ROBOT_FINISH_(3) → M1023

최종 NG: VISION.VISION3_NG → M1124

옛 D200 설명, Python 시험 코드의 PLC_FINISH를 현장 최종 신호와 혼동하지 않음

통신 확인 순서: PLC 연결 → KEPServer 태그 품질 → CIMON 상태 표시 → 주문·공정 이력 일치

로봇 TCP 연결 감시는 연결 유무만 표시. 실제 로봇 동작 성공·공정 완료와 구분

Vision MJPEG 중계는 화면 표시용. 판정 신호와 생산 제어 완료 조건은 별도 확인

이 문서는 비밀번호·실제 주소를 제공하지 않습니다. 운영 계정과 세부 설정은 비공개 원본에서 담당자가 관리합니다.

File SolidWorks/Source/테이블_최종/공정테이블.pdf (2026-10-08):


SOLIDWORKS | . | . 교육용 제품 교수 및 강의 전용

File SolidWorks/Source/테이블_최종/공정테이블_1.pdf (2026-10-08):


SOLIDWORKS | . | . 교육용 제품 교수 및 강의 전용

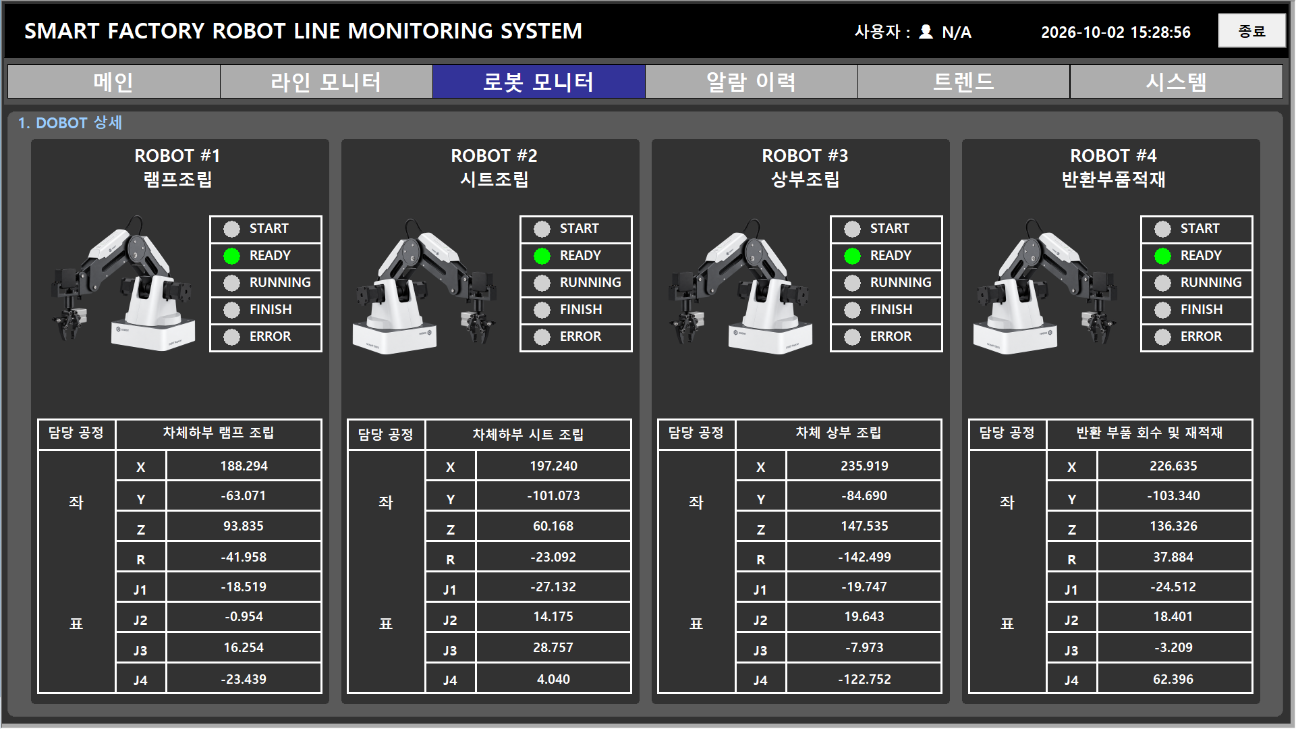
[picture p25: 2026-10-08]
SCADA/screenshots/로봇 모니터.png

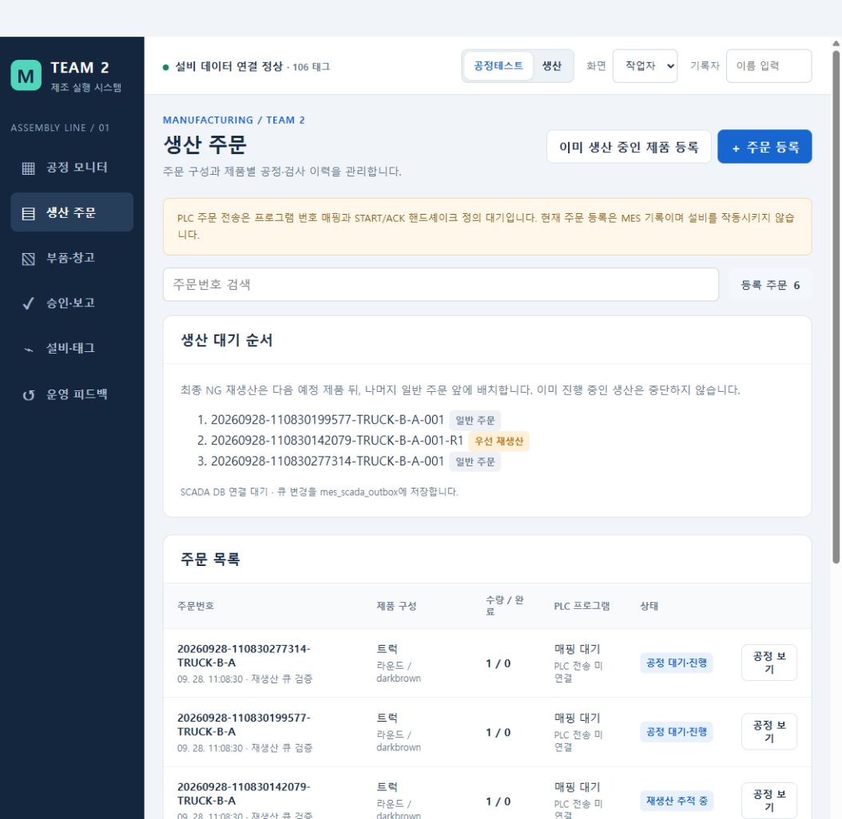
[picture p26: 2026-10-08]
MES/screenshots/03_NG재생산큐.png

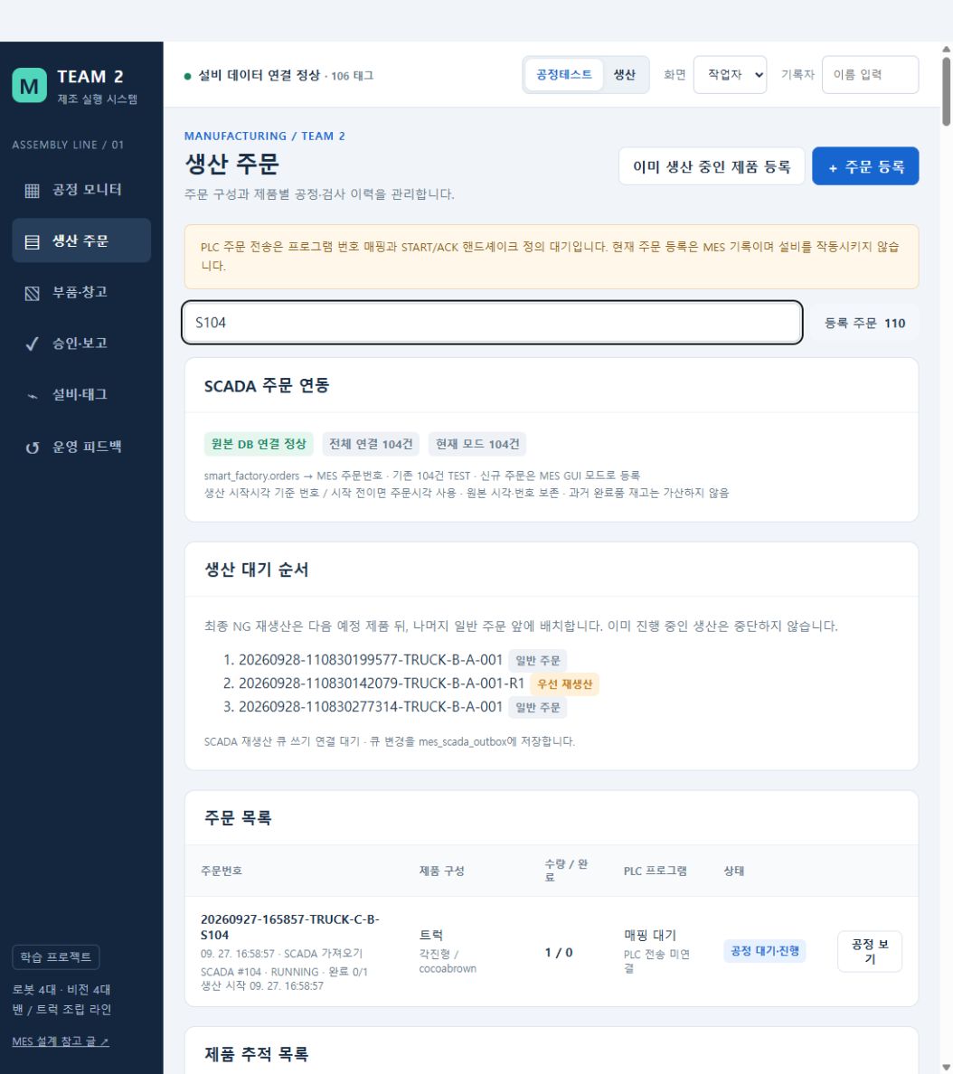
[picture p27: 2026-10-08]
MES/screenshots/02_SCADA주문가져오기.png

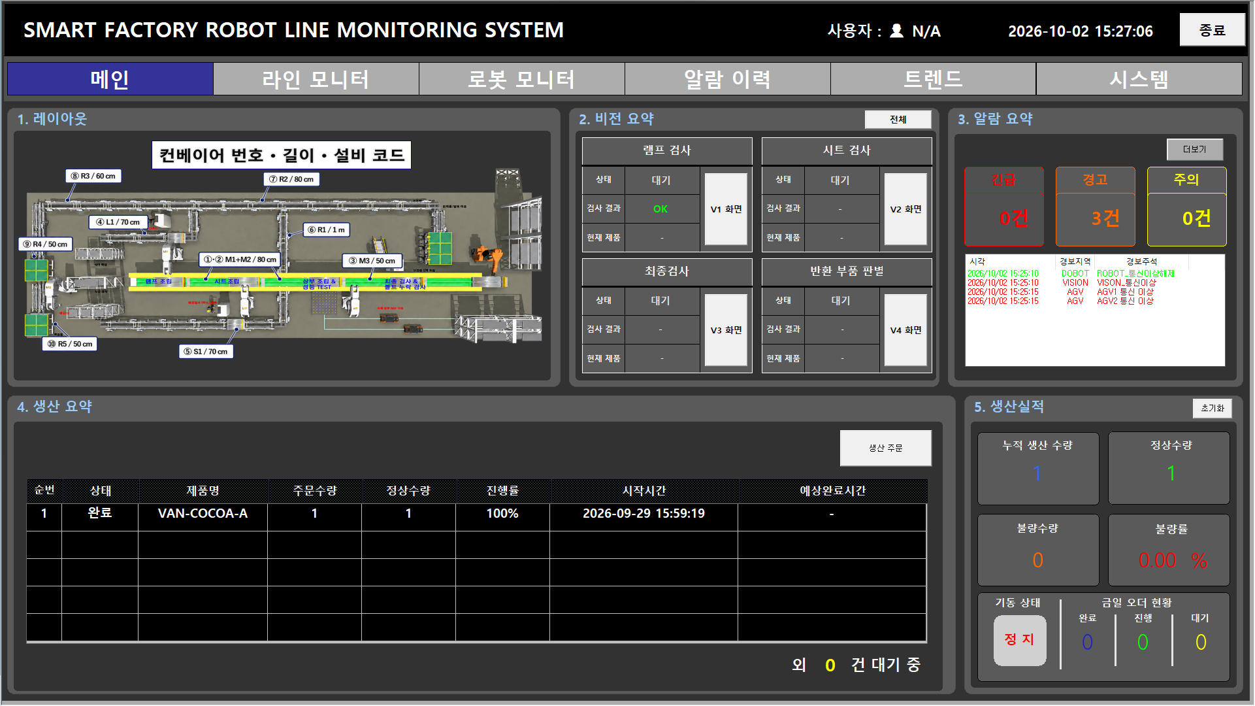
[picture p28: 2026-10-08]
SCADA/screenshots/메인.png

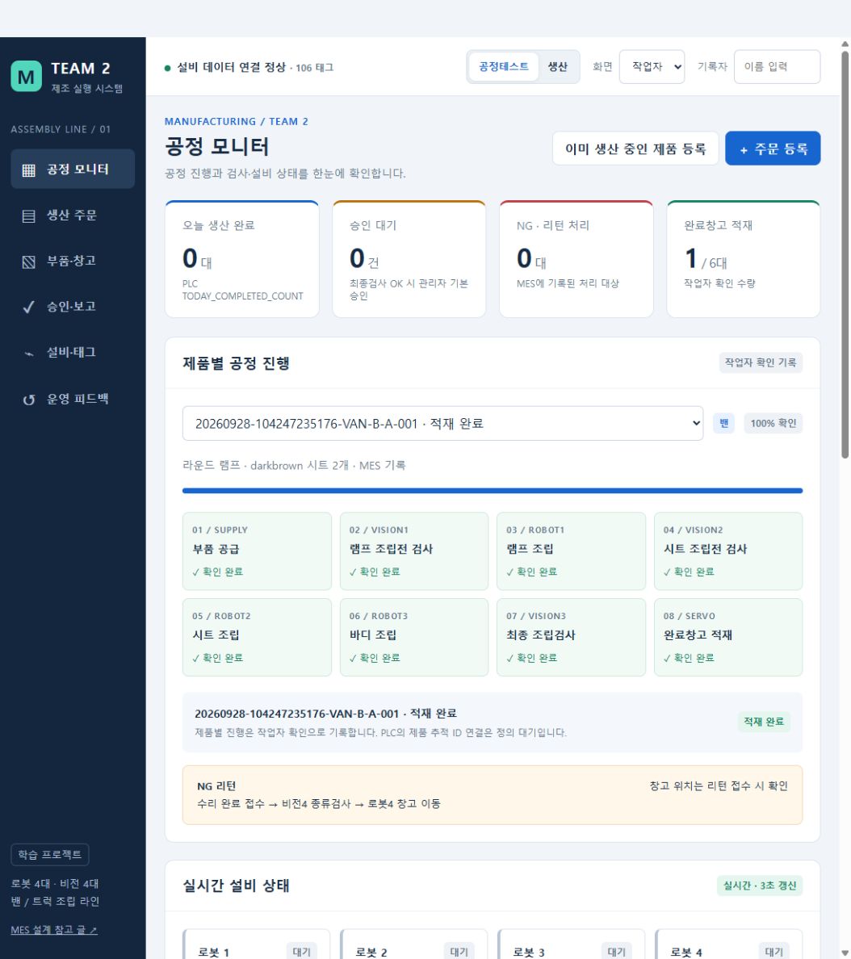
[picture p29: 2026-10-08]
MES/screenshots/01_공정모니터.png

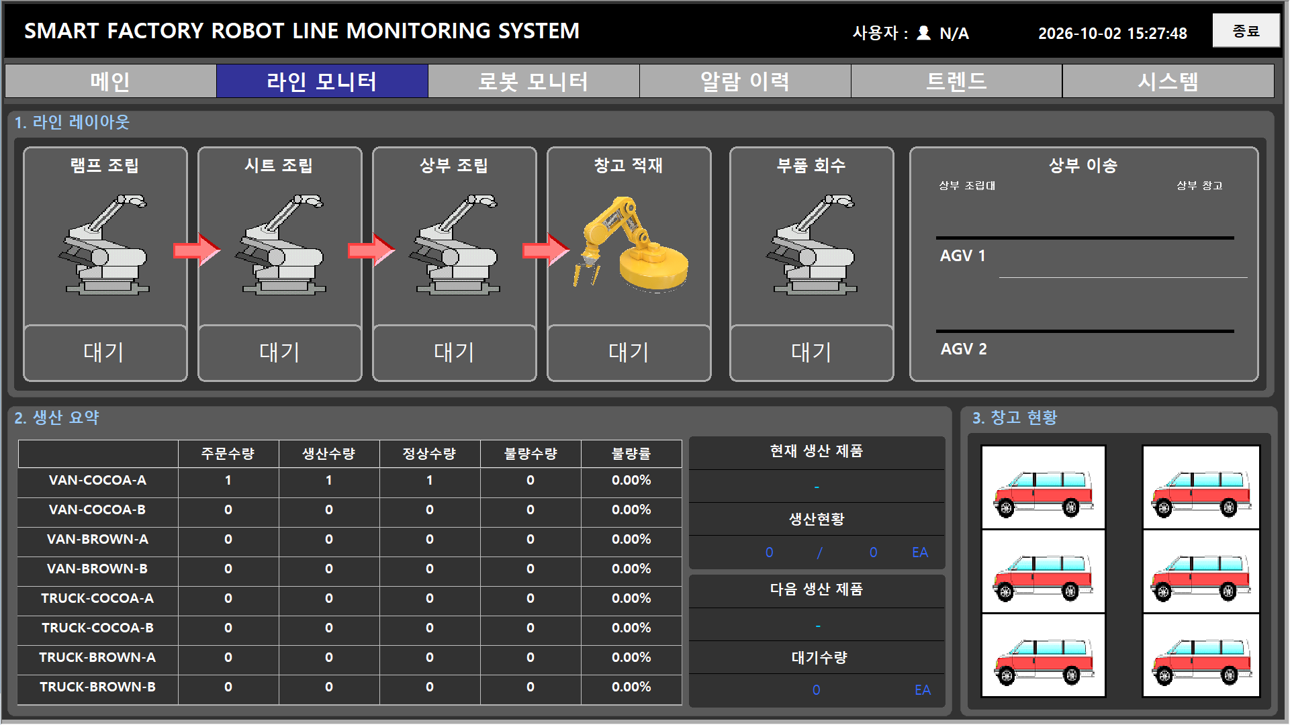
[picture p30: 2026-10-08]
SCADA/screenshots/라인모니터.png

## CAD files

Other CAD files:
SolidWorks/Source/테이블_최종/conveyor/conveyor_Main_50.SLDPRT
SolidWorks/Source/테이블_최종/dobot/두봇_베이스포함.SLDASM
SolidWorks/Source/테이블_최종/item/lamp_fin/lampRound.SLDASM
SolidWorks/Source/테이블_최종/item/truckEdgeDarkbrown.SLDASM
SolidWorks/Source/테이블_최종/Motor/DC모터/GM25-2430 17mm.SLDASM
SolidWorks/Source/테이블_최종/Motor/리니어모터/LM2036U_150MM 3D 도면.SLDASM
SolidWorks/Source/테이블_최종/Roller/lampLine/linier/supply.linieyType.SLDASM
SolidWorks/Source/테이블_최종/Roller/lampLine/supplylinier.lampA.SLDASM
SolidWorks/Source/테이블_최종/Roller/seatlamp/curve/curveSeatB.SLDASM
SolidWorks/Source/테이블_최종/Roller/seatlamp/linier/supplySeat.linieyType.SLDASM
SolidWorks/Source/테이블_최종/vision/logitech-c920.SLDASM
SolidWorks/Source/테이블_최종/공정구상도_수정중.SLDASM
SolidWorks/Source/테이블_최종/dobot/진공펌프.SLDASM
SolidWorks/Source/테이블_최종/item/lamp_fin/lampEdge.SLDASM
SolidWorks/Source/테이블_최종/item/truckEdgeCocoa.SLDASM
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

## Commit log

2026-10-08 Publish final SolidWorks assembly and required components excluding OldVer
    [180D.SLDASM, 2020-400.SLDPRT, 2안.SLDASM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]
2026-10-08 Publish curated SCADA MES and dated PLC ladder portfolio materials
    [1_Main.csv, 2_Body.csv, 3_Lamp.csv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]
